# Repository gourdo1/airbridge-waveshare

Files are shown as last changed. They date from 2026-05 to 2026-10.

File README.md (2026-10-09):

# AirBridge

ESP32 bridge for ResMed AirSense 10 CPAP.

AirBridge feeding oximetry

## What it does

- **Web UI** - configure therapy settings, view sleep reports, live pressure/flow waveforms, and manage oximeters.
- **SD recording and export** - records therapy in Air10 EDF format and synchronizes files to SMB and SleepHQ on [SD-capable hardware](docs/hardware.md#what-needs-sd).
- **Oximetry** - feeds SpO2/pulse into AirSense for native SAD.edf recording. BLE (Nonin 3150, O2Ring, O2Ring-S, Checkme O2, WS20A, generic PLX/HR sensors) and UDP for integrating unsupported devices.
- **ResMed OTA** - upload and flash AirSense firmware over WiFi.
- **TCP-UART bridge** - send commands to AirSense over WiFi.

## First setup

Follow the [Quick Start](docs/quickstart.md) to wire and flash your board.
On a fresh installation, connect to its `airbridge_...` WiFi network
(password `airbridge`), open `http://192.168.4.1/`, and complete the setup wizard.
Default Web UI login: `admin` / `airbridge`.

## Related tools

[airbreak-plus](https://github.com/m-kozlowski/airbreak-plus/tree/master/python/) contains Python tools for direct serial/TCP interaction:

- `python/resmed_flash.py -p tcp:airbridge` - flash AirSense firmware
- `python/resmed_config.py -p tcp:airbridge` - read/write AirSense settings

Both support serial (`-p /dev/ttyUSB0`) and TCP (`-p tcp:hostname`) with `--tcp-mode=raw|transparent|text`.

## Screenshots

| Dashboard | Edf Sync | Charts |
|---|---|---|
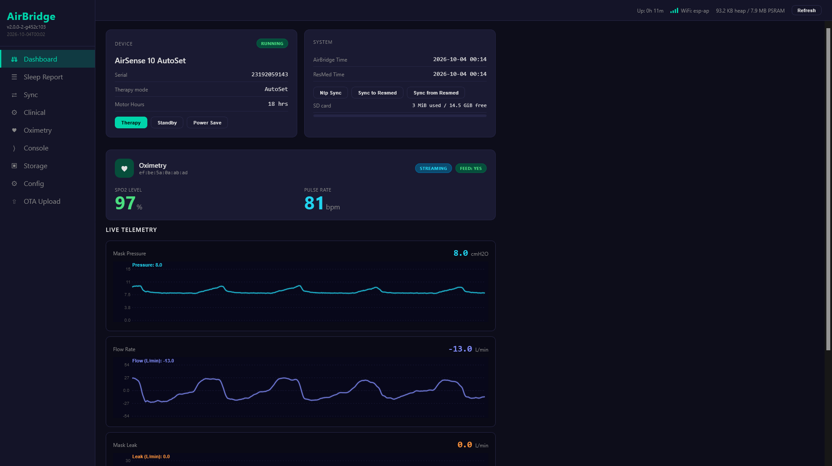
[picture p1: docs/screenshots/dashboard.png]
Dashboard
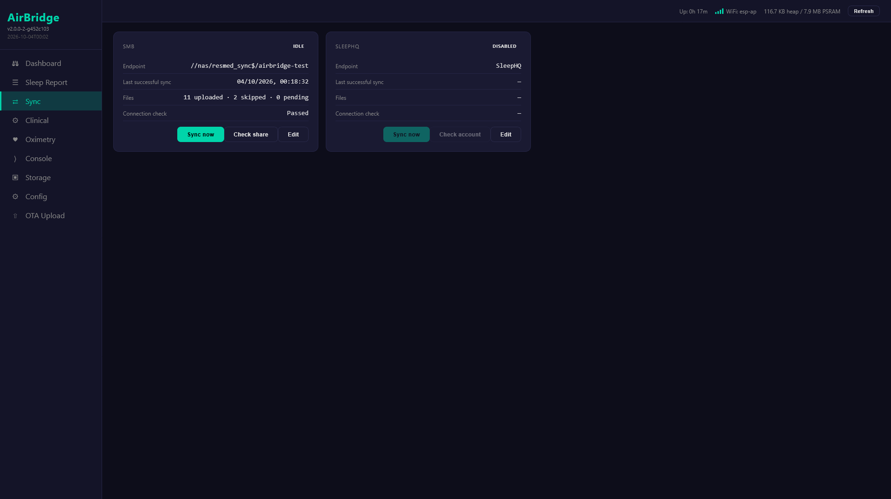
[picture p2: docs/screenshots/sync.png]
Sync
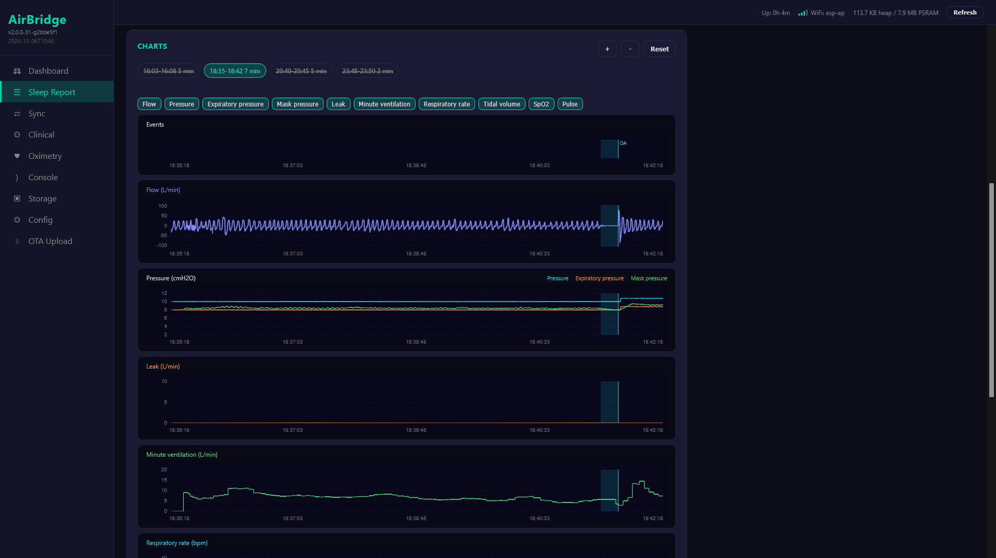
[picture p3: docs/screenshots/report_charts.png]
Charts
|  |  |  |

| Sleep Report | Clinical Settings | Oximetry |
|---|---|---|
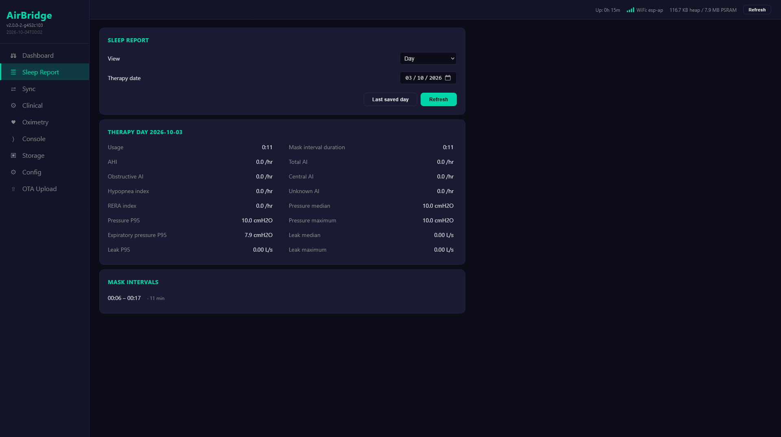
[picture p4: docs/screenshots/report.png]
Report
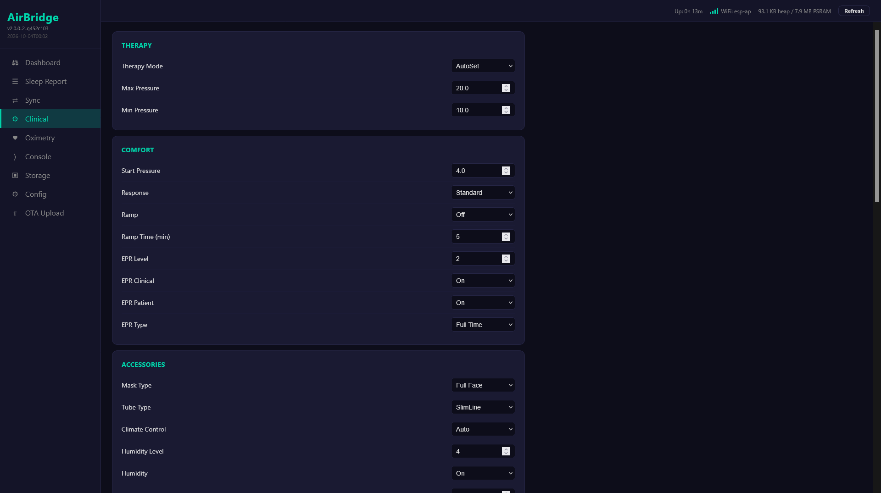
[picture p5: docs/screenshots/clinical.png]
Clinical
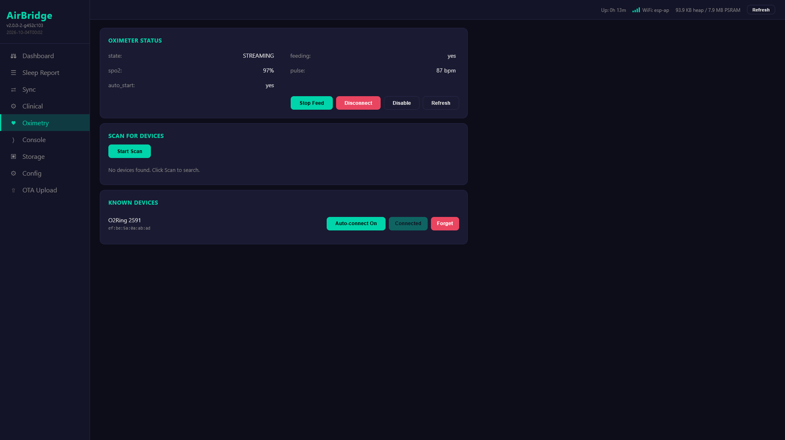
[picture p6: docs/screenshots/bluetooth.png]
Bluetooth
|  |  |  |

## License

GPL v3. See [LICENSE](LICENSE).

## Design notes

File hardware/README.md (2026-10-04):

# Hardware sources

User documentation: [docs/hardware.md](../docs/hardware.md).

| Path | Content |
|---|---|
| `wiring/{xiao_sd,xiao,pico}/` | hand-wired variants (schematic only, local symbol library) |
| `pcb/board_interface/` | interface board (edge card) |
| `pcb/board_main_xiao/` | XIAO main board |
| `pcb/gerbers/` | gerbers, per board as a directory and a ZIP |
| `pcb/assembly/` | JLCPCB BOM/CPL |
| `schematics/` | PDF and PNG export of each schematic |
| `renders/` | 3D renders of the boards |
| `enclosure/xiao/` | STL for the PCB variant |

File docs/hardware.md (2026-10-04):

# Hardware

AirBridge connects to the AirSense 10 edge connector: UART plus +24 V.

## Variants

In order of preference:

| Variant | Build env | SD | Docs |
|---|---|----|---|
| PCB: interface board + XIAO main board | `xiao-esp32s3-plus-sdmmc4` | yes | [hardware_pcb.md](hardware_pcb.md) |
| Hand-wired XIAO ESP32-S3 Plus + microSD | `xiao-esp32s3-plus-sdmmc4` | yes | [hardware_wiring.md](hardware_wiring.md#xiao-esp32-s3-plus--sd) |
| Waveshare ESP32-S3-GEEK | `waveshare-esp32-s3-geek` | onboard | [below](#waveshare-esp32-s3-geek) |
| Waveshare ESP32-S3-LCD-1.54 (UART pads) | `waveshare-s3-lcd154` | onboard | [below](#waveshare-esp32-s3-lcd-154) |
| Waveshare ESP32-S3-LCD-1.54 (SCL/SDA pads) | `waveshare-s3-lcd154-i2cpads` | onboard | [below](#alternate-wiring-sclsda-pads) |
| Hand-wired XIAO ESP32-S3 Plus | `xiao-esp32s3-plus` | no | [hardware_wiring.md](hardware_wiring.md#xiao-esp32-s3-plus-without-sd) |
| Hand-wired M5Stamp Pico (legacy) | `m5stamp-pico` | no | [hardware_wiring.md](hardware_wiring.md#m5stamp-pico-legacy) |

The PCB and the hand-wired XIAO + SD use the same GPIOs and the same firmware.

The M5Stamp Pico has no PSRAM and no SD support. It is kept building, but new
features are not designed around it.

## What needs SD

Requires SD:

- local therapy recording in AirSense EDF format (`DATALOG`, `STR.edf`,
  `Identification`)
- SMB export
- SleepHQ export
- Storage browser (list, download, ZIP, rename, delete)

Works without SD:

- UART/TCP bridge
- live pressure/flow charts
- oximetry (BLE, UDP)
- clinical settings
- Sleep Report
- ResMed OTA and AirBridge OTA

On builds without SD the Sync and Storage tabs are hidden and the SMB/SleepHQ
setup steps are skipped.

## AirSense 10 edge connector

| Left | Right |
|---|---|
| **Tx** | nc |
| **Rx** | **GND** |
| nc | nc |
| nc | nc |
| nc | **+24V**  |

UART: 3.3 V logic, 57600 8N1. AirSense Tx goes to AirBridge RX.

## GPIO

| Signal | XIAO ESP32-S3 Plus | M5Stamp Pico |
|---|---|---|
| UART RX (from AirSense Tx) | GPIO2 (D1) | G36 |
| UART TX (to AirSense Rx) | GPIO1 (D0) | G26 |
| LED | GPIO21 | G27 |

SD, 4-bit SDMMC (`xiao-esp32s3-plus-sdmmc4`):

| CLK | CMD | D0 | D1 | D2 | D3 |
|-----|-----|----|----|----|----|
| GPIO13 | GPIO11 | GPIO12 | GPIO38 | GPIO39 | GPIO40 |

Pins are set by build flags in `platformio.ini`; defaults are in
`include/board.h`. The XIAO SD clock is 40 MHz (`AB_SDMMC_FREQ_KHZ=40000`).

### Waveshare ESP32-S3-GEEK

16 MB flash, 2 MB PSRAM, onboard microSD. The LCD is not used; its backlight
is switched off.

| UART connector | AirSense |
|---|---|
| RX (GPIO44) | Tx |
| TX (GPIO43) | Rx |
| GND | GND |

The onboard card uses 4-bit SDMMC at 40 MHz:

| CLK | CMD | D0 | D1 | D2 | D3 |
|-----|-----|----|----|----|----|
| GPIO36 | GPIO35 | GPIO37 | GPIO33 | GPIO38 | GPIO34 |

Power through the USB-A connector with 5 V, not the AirSense 24 V supply.
Pinout: [Waveshare schematic](https://files.waveshare.com/wiki/ESP32-S3-GEEK/ESP32-S3-GEEK-Schematic1.pdf).

## Power

### XIAO through BAT

The XIAO is fed from a 5 V buck into its **BAT** pad, through a diode
(Schottky when hand-wired, LM66100 ideal diode on the PCB). No battery is
fitted.

- The **5V** pad is USB VBUS. Feeding it would push current into the USB host
  whenever a cable is connected. BAT is the board's own supply input.
- The diode keeps the XIAO charger and USB from backfeeding the buck.
- With the buck powered, BAT is held above the charger's regulation voltage,
  so the charger does not supply charging current.
- USB stays usable for flashing and logs with the device installed.

### Series resistor on +24 V

Hot-plugging a buck module into the AirSense charges its input capacitors hard
enough to trip the AirSense overcurrent protection, which shuts it down.
A ~47 Ω resistor in series with +24 V limits that inrush.

It works, but it is not an optimal solution: it drops voltage and dissipates
power continuously, so it needs a 2 W part. The PCB replaces it with the
eFuse soft-start; see [hardware_pcb.md](hardware_pcb.md#power).

## Waveshare ESP32-S3-LCD-1.54

The `waveshare-s3-lcd154` build target runs on the Waveshare
[ESP32-S3-LCD-1.54](https://www.waveshare.com/esp32-s3-lcd-1.54.htm) and its
touch variant. The AirSense UART uses the board's exposed UART pads:

| Signal | Waveshare pad | GPIO |
|---|---|---|
| AirSense Tx -> AirBridge RX | ESP_RXD | GPIO44 |
| AirSense Rx <- AirBridge TX | ESP_TXD | GPIO43 |
| AirSense GND | GND | - |

GPIO43/44 are the ESP32-S3 UART0 pins, so this target runs the console (logs,
`$` commands, provisioning) over the native USB-C port instead. Nothing but
AirSense traffic is sent on GPIO43 once the firmware is running.

### Alternate wiring: SCL/SDA pads

If the ESP_TXD/ESP_RXD pads are damaged, use the `waveshare-s3-lcd154-i2cpads`
build target (and `waveshare-s3-lcd154-i2cpads-ota` for WiFi updates) and wire
the AirSense to the SCL/SDA pads instead:

| Signal | Waveshare pad | GPIO |
|---|---|---|
| AirSense Tx -> AirBridge RX | SCL | GPIO41 |
| AirSense Rx <- AirBridge TX | SDA | GPIO42 |
| AirSense GND | GND | - |

Don't swap these. SCL/SDA are the board's I2C bus, shared with the IMU, the
audio codecs and (touch variant) the touch controller, with 4.7k pull-ups.
The firmware never uses that bus, but those chips still listen to it:

- I2C chips never drive SCL, so the AirSense's output on SCL is never fought.
- An I2C chip can pull SDA low to acknowledge. AirBridge therefore drives
  SDA open-drain and relies on the 4.7k pull-up for the high level, so
  nothing can short.
- The touch controller is held in reset (GPIO47) to take it off the bus.
- Rarely, when both sides transmit at once and the bits happen to match a
  chip's address, a chip may corrupt a byte. Commands fail their checksum and
  are retried, and a lost oximetry sample is replaced half a second later.

A side benefit: GPIO41/42 aren't the ESP32-S3 console pins, so the boot text
described below never reaches the AirSense on this wiring.

### Power

Set the step-down converter to **3.3V** and feed it into the board's **3V3
pad**, the same way as the M5Stamp Pico. This bypasses the board's own
USB/battery power path and its 3.3V regulator. Keep the 47 Ohm inrush resistor
on the +24V input.

- Trim the converter to 3.3V with a meter **before** connecting it. The 3V3
  rail feeds the ESP32-S3, flash, PSRAM and LCD directly with no protection,
  and 3.6V is the ESP32-S3 absolute maximum.
- Size the converter for at least 500mA. WiFi and BLE together draw short
  current peaks well above the average, and a sagging supply causes brownout
  resets.
- Don't leave a USB-C cable connected while the 3.3V feed is powered for long
  periods. With both connected, the onboard regulator and the external
  converter drive the 3V3 rail in parallel. A short USB flashing or serial
  session is fine, but for long debugging runs disconnect one of the two.
- Leave the battery header empty.

```

    AirSense 10                          Waveshare ESP32-S3-LCD-1.54
    Edge Connector                       +----------------------+
                                         |                      |
    Tx  -------------------------------- ESP_RXD pad (GPIO44)   |
    Rx  -------------------------------- ESP_TXD pad (GPIO43)   |
    GND ----------------+      +-------- GND pad                |
                        |      |    +--> 3V3 pad                |
    +24V ---[47R]--+    |      |    |    +----------------------+
                   |    |      |    |
               +---+----+------+----+----+
               |  IN+  IN-    OUT- OUT+  |
               |        MP1584EN         |
               |       (3.3V out)        |
               +-------------------------+
```

Notes:

- The LCD shows a status screen: IP address, time, AirSense state, mask
  pressure during therapy, and SpO2/pulse when an oximeter is feeding.
  The backlight runs at a low dim level. Pressing any of the three buttons
  (BOOT, GPIO4, GPIO5) raises it to full brightness for 10 seconds. It also
  stays bright for 10 seconds after boot so the IP address can be read. Tune
  the dim level with `-DAB_LCD_DIM_DUTY=<0-1023>` in `platformio.ini` if the
  default (8) is too dark or too bright.
- While therapy is running, the screen subscribes to the AirSense's 25 Hz
  pressure stream (the same one the web UI's live graph uses) and shows a
  one-second average.
- GPIO2 (battery power latch) is driven high at boot. This only matters when
  the board runs from a LiPo, and does nothing when powered through the 3V3 pad.
- The ESP32-S3 boot ROM prints a short burst of text on GPIO43 at 115200 baud
  right after reset, before the firmware starts. The AirSense sees it as line
  noise and the firmware's health polling recovers. If it ever causes trouble,
  the ROM output can be disabled permanently by burning the
  `UART_PRINT_CONTROL` eFuse (irreversible).
- The onboard TF card slot is used for SD recording and export (see
  [What needs SD](#what-needs-sd)). It is 4-bit SDMMC at 20 MHz:

  | CLK | CMD | D0 | D1 | D2 | D3 |
  |-----|-----|----|----|----|----|
  | GPIO16 | GPIO15 | GPIO17 | GPIO18 | GPIO13 | GPIO14 |

- Partition table: `partitions_s3_16mb.csv` (two 7.75 MB app slots plus a
  crash-dump partition). A board still on the older 8 MB layout keeps working
  after a WiFi update, but only gets the new layout (and crash dumps) after
  one USB flash of the complete image: `pio run -e <env> -t upload`, or
  `pio run -e <env> -t initialbin` and then `firmware.factory.bin` at
  address `0x0` in a web flasher.

## Enclosure

3D-printable enclosure for the PCB variant:
[airbridge-xiao.stl](../hardware/enclosure/xiao/airbridge-xiao.stl).

## Sources

KiCad projects, PDFs, gerbers and assembly files are in
[`hardware/`](../hardware/README.md).

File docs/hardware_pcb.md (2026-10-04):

# PCB

Two boards:

- **interface**: edge card that plugs into the AirSense 10. Protected 24 V
  input, 5 V buck, UART.
- **main**: XIAO ESP32-S3 Plus and 4-bit microSD.

The boards are joined by a 5-pin, 1.27 mm solder-pin connector.
Build env: `xiao-esp32s3-plus-sdmmc4`. GPIO and SD features:
[hardware.md](hardware.md).

| Interface | Main |
|---|---|
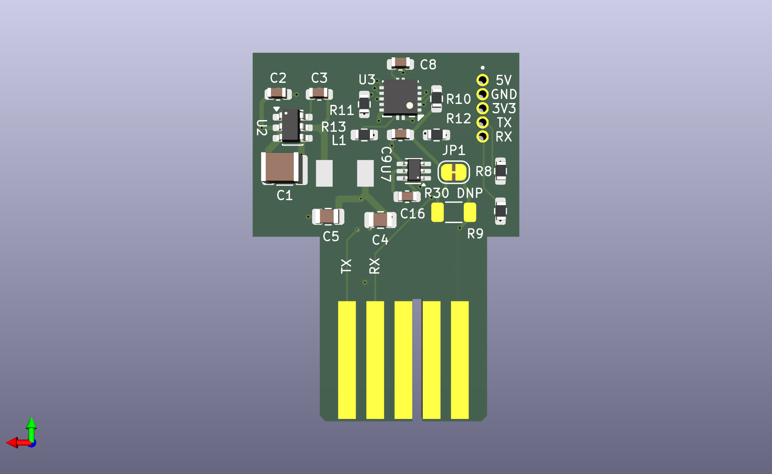
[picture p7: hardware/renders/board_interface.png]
interface board
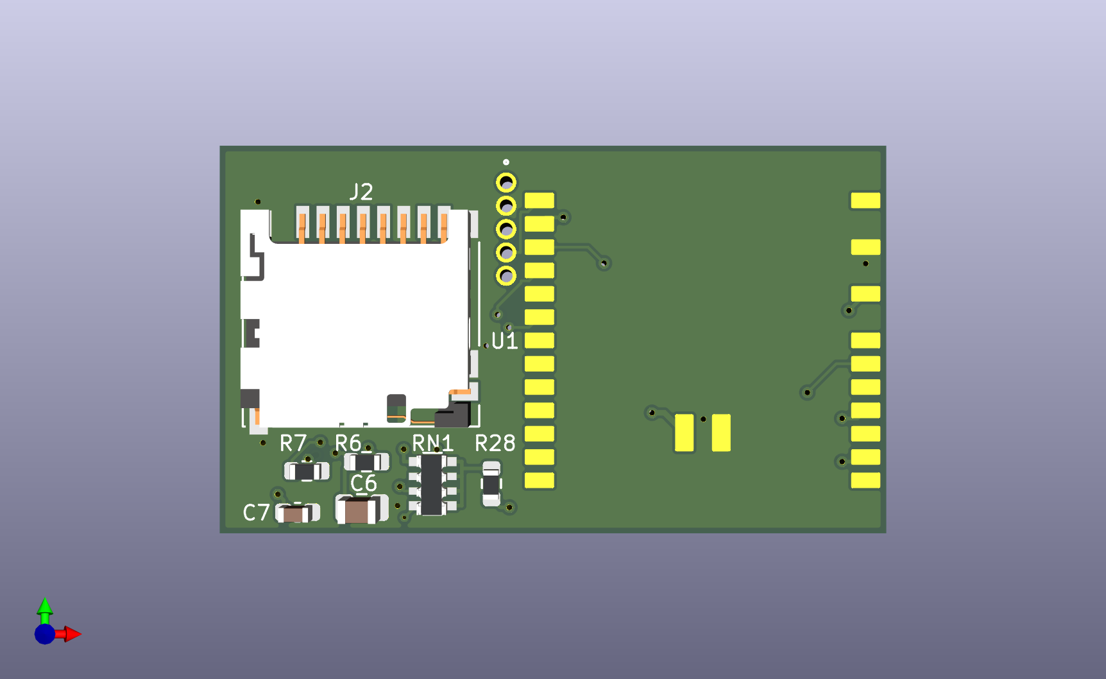
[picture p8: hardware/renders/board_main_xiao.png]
main board
|  |  |

## Interface board

[KiCad project](../hardware/pcb/board_interface/),
PDF: [board_interface.pdf](../hardware/schematics/board_interface.pdf).

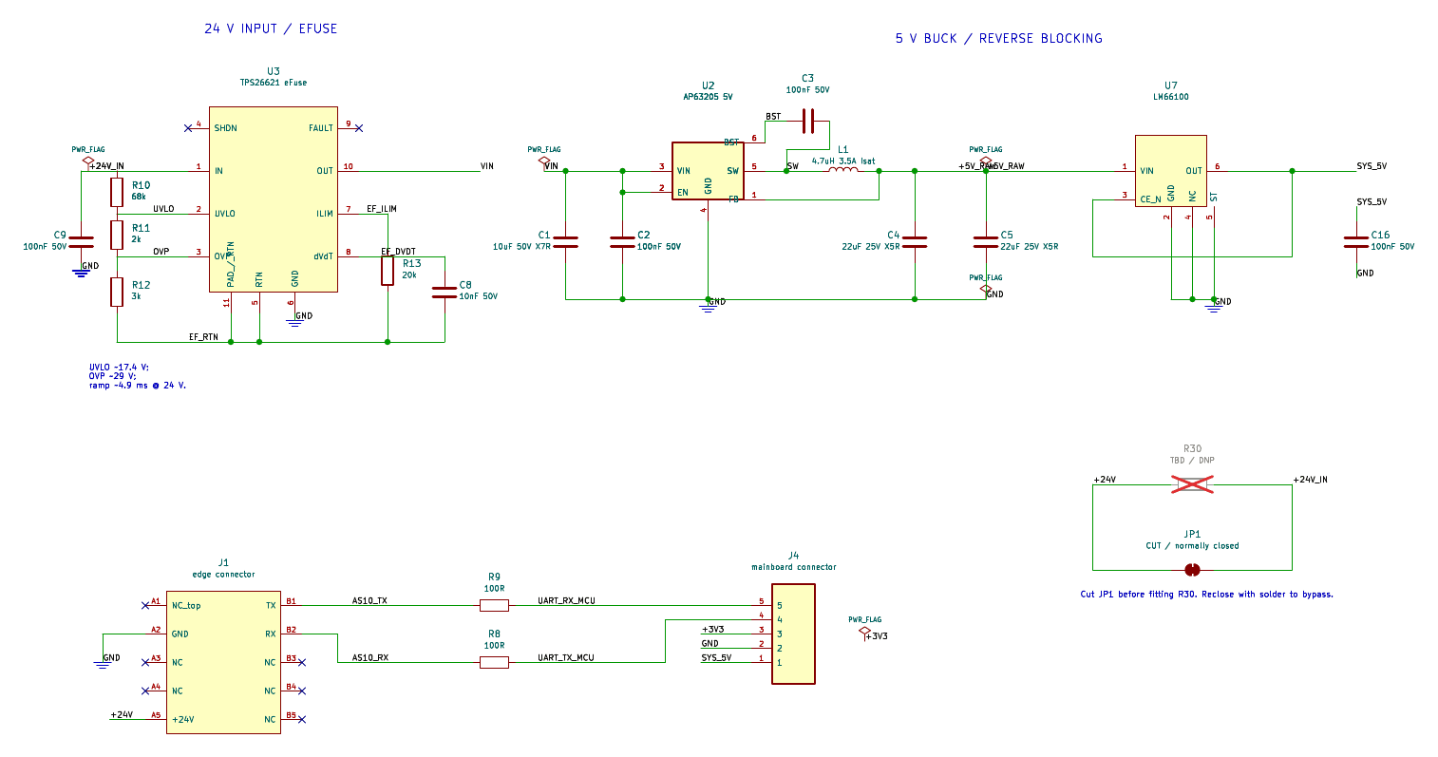
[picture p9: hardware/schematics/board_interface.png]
interface schematic


### Power

- **TPS26621 eFuse** on +24 V: UVLO ~17.4 V, OVP ~29 V, dV/dt soft-start
  ~4.9 ms at 24 V. The soft-start replaces the series resistor used in
  hand-wired builds, so hot-plugging does not trip the AirSense.
- **AP63205** 5 V buck.
- **LM66100** ideal diode between the buck and `SYS_5V`. It does the job of the
  Schottky in hand-wired builds, without the drop.

R30 (1206, not fitted) is an optional series resistor on +24 V, bypassed by
the JP1 solder jumper. Cut JP1 before fitting R30; bridge it with solder to
go back.

### UART

AirSense TX/RX go through 100 Ω series resistors to the interboard connector.

### Interboard connector

| Pin | Signal |
|-----|---|
| 1 | SYS_5V |
| 2 | GND |
| 3 | +3V3 |
| 4 | UART_TX_MCU (to AirSense RX) |
| 5 | UART_RX_MCU (from AirSense TX) |

## Main board

[KiCad project](../hardware/pcb/board_main_xiao/),
PDF: [board_main_xiao.pdf](../hardware/schematics/board_main_xiao.pdf).

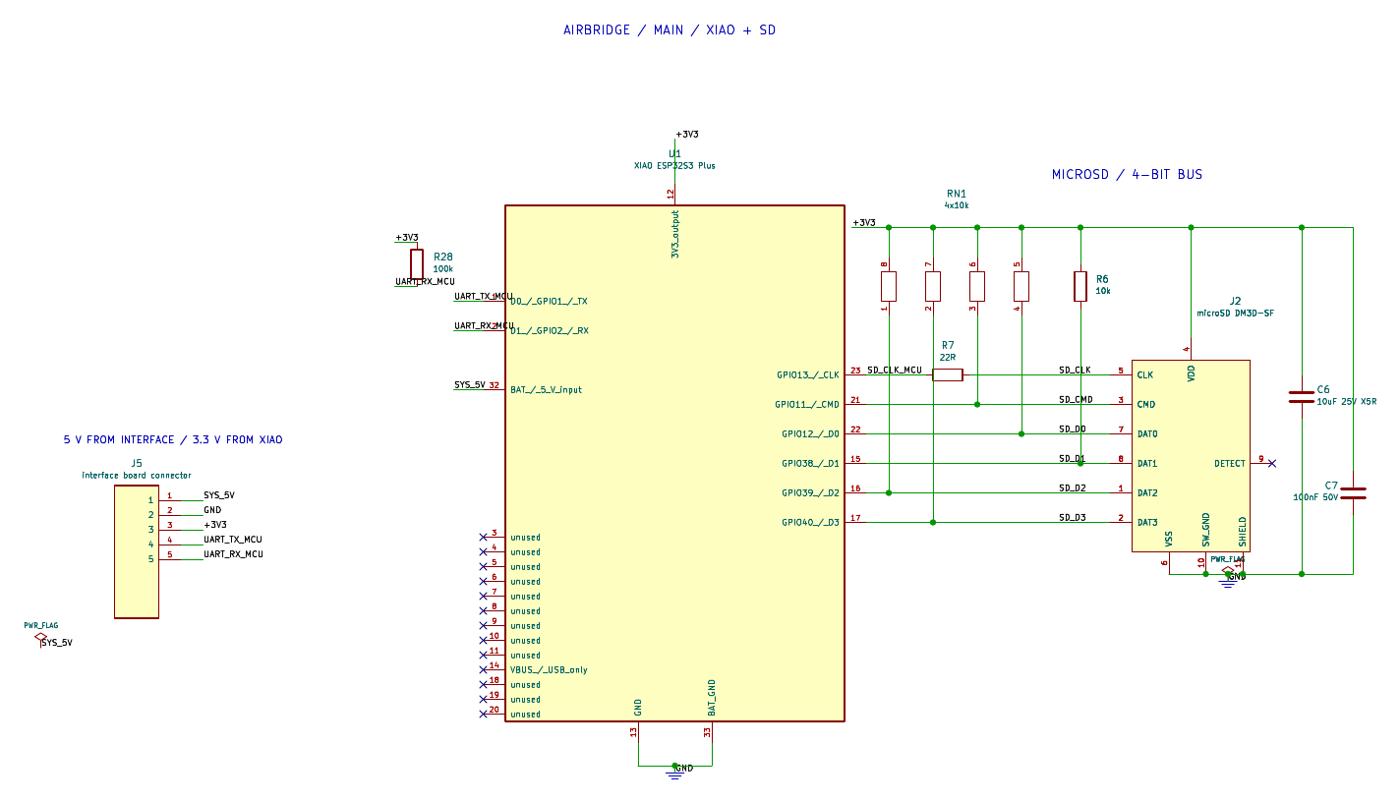
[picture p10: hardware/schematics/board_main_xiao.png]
main schematic


- XIAO ESP32-S3 Plus soldered onto pads; `SYS_5V` feeds its BAT input (see
  [hardware.md](hardware.md#xiao-through-bat)).
- Hirose DM3D-SF microSD socket powered from XIAO 3V3.
- 10 kΩ pull-ups on CMD and D0–D3, 22 Ω series resistor on CLK, 10 µF +
  100 nF at the socket.
- 100 kΩ pull-up on UART RX.

## Ordering

Both boards: 4 layers, 1.6 mm. Tinned (HASL) edge fingers are good enough.

| Board | Gerbers | BOM | CPL |
|---|---|-----|-----|
| interface | [interface.zip](../hardware/pcb/gerbers/interface.zip) | [bom-interface.csv](../hardware/pcb/assembly/bom-interface.csv) | [cpl-interface.csv](../hardware/pcb/assembly/cpl-interface.csv) |
| main | [main_xiao.zip](../hardware/pcb/gerbers/main_xiao.zip) | [bom-main-xiao.csv](../hardware/pcb/assembly/bom-main-xiao.csv) | [cpl-main-xiao.csv](../hardware/pcb/assembly/cpl-main-xiao.csv) |

BOM/CPL are in JLCPCB format with LCSC part numbers. Not included: the XIAO
module and the interboard pins, both soldered by hand.

Enclosure: [airbridge-xiao.stl](../hardware/enclosure/xiao/airbridge-xiao.stl).

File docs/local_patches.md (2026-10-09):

# Local patches to third-party code

Workarounds for bugs in libraries or frameworks that AirBridge builds
against. Each entry says how to tell when the upstream fix has landed, so the
local copy can be removed. Check this list whenever the pioarduino platform
or Arduino core version in `platformio.ini` changes, and before merging
upstream AirBridge.

## SD_MMC drops `SDMMC_HOST_FLAG_DEINIT_ARG` (arduino-esp32)

| | |
|---|---|
| Patched | 2026-10-07 |
| Where | [`lib/SD_MMC/`](../lib/SD_MMC/README.md), copied from arduino-esp32 3.3.7 |
| Affects | Every SD-capable build. Visible on Waveshare ESP32-S3-LCD-1.54, where GPIO0 is a button |
| Symptom | After an SD unmount or failed mount, GPIO0's input buffer is switched off and the left button reads as permanently pressed. `$LCD` shows `ie=0 pu=1` for GPIO0 |
| Cause | `SDMMCFS::begin()` overwrites `host.flags`, losing `SDMMC_HOST_FLAG_DEINIT_ARG`; ESP-IDF then calls `sdmmc_host_deinit_slot()` without a slot number and may release the unused slot 0, resetting GPIO0 |
| Upstream status | Not fixed in arduino-esp32 3.3.7, 3.3.12 or `master` (2026-10-07) |
| Remove when | The arduino-esp32 version AirBridge builds against keeps `SDMMC_HOST_FLAG_DEINIT_ARG` in `SD_MMC.cpp`. Then delete `lib/SD_MMC/` and this entry |

Details and the exact two-line change: [`lib/SD_MMC/README.md`](../lib/SD_MMC/README.md).

## `.patch` files checked out as CRLF on Windows (upstream AirBridge)

| | |
|---|---|
| Patched | 2026-10-09 |
| Where | [`.gitattributes`](../.gitattributes): `*.patch text eol=lf` |
| Affects | Every build on Windows with `core.autocrlf=true`, all targets |
| Symptom | Build fails in `python/tools/library_patches.py` (`git apply` returns an error) while generating `WebResponses.cpp` |
| Cause | Upstream v2.1.1 applies `patches/espasyncwebserver/*.patch` with `git apply` at build time. Git converts the patch to CRLF on checkout; the library source is LF, so no hunk matches |
| Upstream status | No `.gitattributes` in upstream v2.1.1 (2026-10-09) |
| Remove when | Upstream adds an equivalent rule (any `.gitattributes` that keeps `*.patch` LF), or stops applying patches with `git apply`. Then drop this file or merge it with upstream's |

## Build middleware ignored on Windows (pioarduino platform)

| | |
|---|---|
| Patched | 2026-10-09 |
| Where | [`python/tools/extend_asyncwebserver.py`](../python/tools/extend_asyncwebserver.py) (upstream AirBridge script, fork-modified) |
| Affects | Every build on Windows, all targets |
| Symptom | Build fails in `library_patches.py`: `git apply` reports `.../generated/tmpXXXX/WebResponses.cpp: No such file or directory` (the temp folder holds `ColorFormat.c`) |
| Cause | On Windows, pioarduino 55.03.37 (`builder/frameworks/arduino.py`, `integrated_middleware`) replaces all registered build middlewares with one wrapper that calls each of them for every source file, ignoring their patterns, and compiles the original source, ignoring the node they return. Upstream's middleware therefore ran for the wrong file, and its patched replacement would never be compiled anyway |
| Fix | The middleware checks the file name itself, and on Windows applies the patch to the installed library copy in place (once; a reverse `git apply --check` detects an applied patch). Linux/macOS keep upstream's generated-copy behaviour |
| Upstream status | Present in pioarduino 55.03.37 and upstream AirBridge v2.1.1 (2026-10-09) |
| Remove when | pioarduino honours middleware patterns and return values on Windows, or upstream AirBridge handles Windows itself. Then restore upstream's `extend_asyncwebserver.py` |

After adding the `.gitattributes` rule, refresh existing checkouts once:
`git rm --cached -r patches && git checkout -- patches` (or delete the `.patch`
files and `git checkout -- patches`).

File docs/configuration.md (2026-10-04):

# Configuration

Settings are stored in NVS (non-volatile storage) and persist across reboots.

## How to configure

**Web UI:** Config tab -> choose a category -> edit fields -> Save & Persist

**CLI:** `$CONFIG key value` then `$CONFIG SAVE`

**Provisioning:** Copy `provision.env.example` to `provision.env`, fill in
your values, and flash. `provision.py` runs after the upload completes and
applies each line via the appropriate command:

- Most keys go through `$CONFIG key value`.
- `wifi_net=SSID PASSWORD` is routed through `$WIFI ADD ssid pass`. Use
  shell-style double quotes if either field contains spaces:
  `wifi_net="My Network" "correct horse battery staple"`. Multiple
  `wifi_net=` lines provision multiple networks (up to 4). Provisioning
  appends; existing networks on the device are kept.

## Settings reference

### WiFi & Network

WiFi networks are managed as a list (up to 4 SSIDs) via the web UI's WiFi
Networks card or the `$WIFI ADD ssid pass` / `$WIFI REMOVE N` commands. The
top-level WiFi-related config keys are:

| Key | Default | Description |
|-----|---|---|
| `hostname` | airbridge | DHCP hostname and AP SSID prefix |
| `wifi_mode` | 1 | Operating mode, see table below |
| `wifi_roam` | true | Roam automatically between saved networks |
| `wifi_country` | 01 | ISO 3166 country code; "01" = worldwide |

**`wifi_mode` values:**

| Value | Name | Behavior |
|---|---|---|
| 0 | auto | Connect to a saved network; use AP fallback while disconnected. |
| 1 | AP only | Access point only; does not connect to saved networks. |
| 2 | off | WiFi disabled entirely (serial/UART only). |
| 3 | STA only | Connect to saved networks without AP fallback. |
| 4 | STA+AP always | Keep the access point available while connecting to saved networks. |

The softAP (when used) is named `<hostname>_<MAC>` with password `airbridge`,
and serves the web UI at `192.168.4.1`.

With no saved networks, Auto and STA+AP modes provide an access point for
setup. STA-only does not start an access point.

The `wifi_country` key affects channel allocation and TX power limits per
regulatory domain. Use a 2-letter ISO code (`US`, `DE`, `JP`, `PL`, ...) or
`01` to use the worldwide-safe defaults. Bad values are rejected with a
log warning and the previous setting stays in effect.

### Web UI

| Key | Default | Description |
|-----|---|---|
| `http_port` | 80 | Web server port |
| `http_user` | admin | Web UI username |
| `http_pass` | airbridge | Web UI password |

### OTA

| Key | Default | Description |
|-----|---|---|
| `update_url` | GitHub latest-release manifest | Release manifest URL; empty disables update checks |

Update checks are automatic. Installing an available update requires
confirmation on the OTA tab.

### Time & Timezone

| Key | Default | Description |
|-----|---|---|
| `ntp_server` | *(empty)* | NTP server address. Empty = use DHCP-provided server, or pool.ntp.org as fallback |
| `tz` | UTC0 | POSIX timezone string (e.g. `CET-1CEST,M3.5.0,M10.5.0/3`) |
| `resmed_time` | 1 | Automatically synchronize the ResMed clock from NTP while idle. `0` disables automatic synchronization; manual sync remains available |

**Config > Time** includes a helper for detecting your browser's timezone.

If NTP is unavailable, the ResMed clock supplies an approximate time for
AirBridge, independently of `resmed_time`.

### Storage export

SMB and SleepHQ export require SD support and a mounted card. Both are disabled
by default. Automatic export sends pending recordings after startup and therapy,
only while therapy is inactive.

| Key | Default | Description |
|-----|---|---|
| `smb_enabled` | false | Enable SMB export |
| `smb_auto_after_therapy` | true | Automatically sync pending recordings after startup and therapy |
| `smb_endpoint` | *(empty)* | Destination in `//host/share/optional/path` form |
| `smb_user` | *(empty)* | SMB username |
| `smb_password` | *(empty)* | SMB password |
| `sleephq_enabled` | false | Enable SleepHQ export |
| `sleephq_auto_after_therapy` | true | Automatically sync pending recordings after startup and therapy |
| `sleephq_client_id` | *(empty)* | SleepHQ API client ID |
| `sleephq_client_secret` | *(empty)* | SleepHQ API client secret |
| `sleephq_team_id` | *(empty)* | Optional numeric team ID; current team is resolved when empty |
| `sleephq_device_id` | *(empty)* | Optional SleepHQ device ID attached to new imports |

### Oximetry

| Key | Default | Description |
|-----|---|---|
| `oxi_enabled` | true | Enable BLE oximeter support |
| `oxi_auto_start` | true | Start feeding data automatically on connect |
| `oxi_feed_therapy_only` | false | Only inject readings during active therapy |
| `oxi_interval_ms` | 500 | Injection interval in milliseconds |
| `oxi_lframe_continuous` | true | Send L-frames even when no valid reading (keeps link alive) |
| `udp_oxi_port` | 8025 | UDP oximetry listener port, 0 = disabled |

BLE oximeters are managed from the **Oximetry** tab. For UDP oximetry, see [udp_oximetry.md](udp_oximetry.md).

Only one source feeds at a time. First to deliver data wins, 10 seconds of silence releases.

### UART

| Key | Default | Description |
|-----|---|---|
| `tcp_port` | 23 | TCP command port |
| `allow_transparent_during_therapy` | false | Allow raw UART passthrough during therapy |
| `uart_cmd_timeout_ms` | 500 | Command response timeout |

### Logging

| Key | Default | Description |
|-----|---|---|
| `debug_port` | 8023 | Debug log stream port (read-only) |
| `syslog_en` | 0 | Enable UDP syslog forwarding |
| `syslog_host` | *(empty)* | Syslog server IPv4 address; required for forwarding |
| `syslog_port` | 514 | Syslog server UDP port (1-65535) |

## CLI commands

All commands are prefixed with `$`. Anything without `$` is sent to the AirSense as a Q-frame command.

| Command | Description |
|---|---|
| `$STATUS` | System state, oximetry, UART stats, heap |
| `$TIME` | Show UTC, local time, timezone, NTP sync state |
| `$TIMESYNC` | Re-trigger ResMed clock sync from NTP |
| `$OXI SCAN` | Scan for BLE oximeters |
| `$OXI RESULTS` | Show scan results |
| `$OXI CONNECT [addr]` | Connect to oximeter |
| `$OXI DISCONNECT` | Disconnect oximeter |
| `$OXI START` / `STOP` | Start/stop data injection |
| `$OXI STATUS` | Oximeter connection details |
| `$CONFIG` | Dump all config |
| `$CONFIG key` | Get single value |
| `$CONFIG key value` | Set value (not saved until SAVE) |
| `$CONFIG SAVE` | Persist to NVS |
| `$CONFIG RESET` | Reset all to defaults |
| `$EXPORT STATUS` | Show SMB and SleepHQ state, progress, and last error |
| `$EXPORT SMB` | Sync pending recordings to SMB |
| `$EXPORT SLEEPHQ` | Sync pending recordings to SleepHQ |
| `$WIFI` / `$WIFI STATUS` | Connection state, RSSI, roaming flag |
| `$WIFI LIST` | List configured networks |
| `$WIFI ADD ssid pass` | Add a network (max 4) |
| `$WIFI REMOVE N` | Remove network at index N |
| `$WIFI HINTS` | Show cached BSSID/channel/PMF hints |
| `$WIFI HINTS CLEAR` | Drop all cached hints |
| `$FLASH [block] [FORCE]` | Flash uploaded ResMed firmware |
| `$FLASH STATUS` | Flash progress |
| `$FLASH CANCEL` | Abort flash |
| `$LOG` | Show log levels |
| `$LOG category level` | Set log level (ERROR/WARN/INFO/DEBUG) |
| `$TRANSPARENT` | Raw UART passthrough (60s idle timeout) |
| `$FRAMED` | Switch to framed UART mode |
| `$VERSION` | Firmware version |
| `$REBOOT` | Restart device |

Log categories: `GENERAL`, `OXI`, `TCP`, `WIFI`, `OTA`, `WEB`, `ARB`, `HEALTH`,
`EXPORT`, `EDF`, `STREAM`, `STORAGE`, `TIME`, `CONFIG`, `REPORT`, `ALL`

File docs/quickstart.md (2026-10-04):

# Quick Start

## What you need
- AirBridge hardware: the PCB, or a hand-wired XIAO ESP32-S3 Plus with or
  without SD. See [hardware.md](hardware.md) for variants and which features
  need SD.
- AirSense 10 with edge connector access
- A computer with Chrome or Edge and a USB data cable

## Wiring

PCB: [hardware_pcb.md](hardware_pcb.md).
Hand-wired: [hardware_wiring.md](hardware_wiring.md).

## Flash firmware

Download the `-initial.zip` matching your board from the
[latest release](https://github.com/m-kozlowski/airbridge/releases/latest)
and extract the `-initial.bin` image.

Open [ESPWebTool](https://esptool.spacehuhn.com/) in Chrome or Edge:

1. Connect the board over USB. M5Stamp Pico needs a 3.3 V USB-to-serial adapter.
2. Select **Connect** and choose its serial port.
3. Add the extracted `-initial.bin` at address `0x0`.
4. Select **Program** and wait for flashing to finish.

### Build from source instead

Install PlatformIO and check out the matching release tag.

XIAO with SD (PCB or hand-wired):

```bash
pio run -e xiao-esp32s3-plus-sdmmc4 -t upload
```

XIAO without SD:

```bash
pio run -e xiao-esp32s3-plus -t upload
```

M5Stamp Pico (legacy):

```bash
pio run -e m5stamp-pico -t upload
```

Waveshare ESP32-S3-LCD-1.54, AirSense wired to the UART pads or to the
SCL/SDA pads (see [hardware.md](hardware.md#waveshare-esp32-s3-lcd-154)).
These boards are not in the release images, so always build from source:

```bash
pio run -e waveshare-s3-lcd154 -t upload
pio run -e waveshare-s3-lcd154-i2cpads -t upload
```

If the upload can't connect, hold **BOOT** while plugging in the USB cable.
The USB port briefly disappears while the board resets after flashing; if the
automatic provisioning step misses it, run `python provision.py <serial port>`
again by hand.

## Configure WiFi

On a fresh installation, connect to the `airbridge_...` WiFi access point
(password `airbridge`) and open `http://192.168.4.1/`.

Log in with username `admin` and password `airbridge`. The setup wizard guides
you through your WiFi network, AirSense connection, time, optional sync
destinations, and Web UI credentials. Use **Save & next**, then **Finish**.
You can reopen the wizard from **Config > Initial setup**.

When flashing with PlatformIO, you can instead copy `provision.env.example`
to `provision.env` and fill in your WiFi credentials before flashing. These
settings are applied automatically after the USB upload.

## Verify it works

Once connected to your WiFi, open `http://airbridge/`. If the hostname does
not resolve, use the device IP from your router's DHCP leases.

The **Dashboard** should show the AirSense name and serial number. With the
AirSense powered on, connected, and not running therapy, its state is
`IDLE`.

See [Configuration](configuration.md) for available settings.

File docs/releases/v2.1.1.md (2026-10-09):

### Reliability fixes

- Fixed stalled or interrupted file and ZIP downloads from Storage.
- Fixed rare crash during Bluetooth initialization.

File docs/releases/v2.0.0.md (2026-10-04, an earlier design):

### EDF recording and synchronization

Record AirSense 10 therapy directly to AirBridge's microSD card in
ResMed-compatible EDF format, with automatic synchronization to an SMB
share, SleepHQ, or both.

Requires an SD-capable build and a microSD card in AirBridge.

### New hardware

AirBridge now has a dedicated two-board PCB design: an interface board that
plugs into the AirSense 10 and provides power and UART, and a XIAO ESP32-S3
Plus main board with microSD for EDF recording. KiCad sources, manufacturing
files, and a printable enclosure are included.

Waveshare ESP32-S3-GEEK is also supported, using its onboard microSD slot.

M5Stamp Pico remains a legacy build without EDF recording or synchronization.

### Upgrading

AirBridge firmware updates now use HTTP through the Web UI or the Python
flasher. ArduinoOTA and its dedicated upload environments have been removed.
SmartConfig has been replaced by setup through the AirBridge access point.

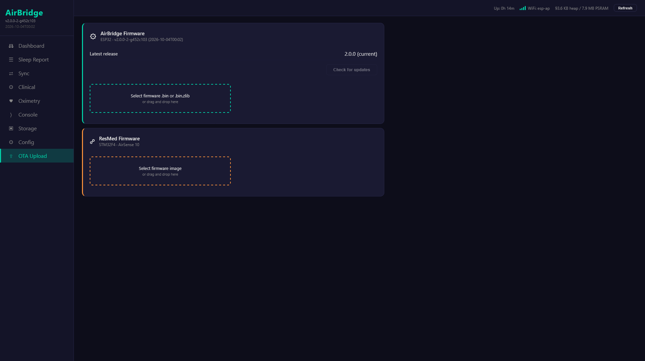
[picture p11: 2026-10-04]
docs/screenshots/ota.png

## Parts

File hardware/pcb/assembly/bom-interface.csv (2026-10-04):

Comment | Designator | Footprint | LCSC Part # | Quantity
CL32B106KBJNNNE | C1 | C_1210_3225Metric | C138687 | 1
CC0603KRX7R9BB104 | C2,C3,C9,C16 | C_0603_1608Metric | C14663 | 4
CL21A226MAQNNNE | C4,C5 | C_0805_2012Metric | C45783 | 2
0603B103K500NT | C8 | C_0603_1608Metric | C57112 | 1
SRP4020TA-4R7M | L1 | L_SRP4020TA | C2041623 | 1
0603WAF1000T5E | R8,R9 | R_0603_1608Metric | C22775 | 2
0603WAF6802T5E | R10 | R_0603_1608Metric | C23231 | 1
0603WAF2001T5E | R11 | R_0603_1608Metric | C22975 | 1
0603WAF3001T5E | R12 | R_0603_1608Metric | C4211 | 1
0603WAF2002T5E | R13 | R_0603_1608Metric | C4184 | 1
AP63205WU-7 | U2 | SOT-23-6 | C2071056 | 1
TPS26621DRCR | U3 | VSON-10-1EP_3x3mm_P0.5mm_EP1.65x2.4mm | C1848341 | 1
LM66100DCKR | U7 | SOT-363_SC-70-6 | C2869734 | 1

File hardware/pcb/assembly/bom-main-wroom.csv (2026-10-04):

Comment | Designator | Footprint | LCSC Part # | Quantity
CL21A106KAYNNNE | C6,C14,C17 | C_0805_2012Metric | C15850 | 3
CC0603KRX7R9BB104 | C7,C11,C15,C18,C19 | C_0603_1608Metric | C14663 | 5
CL10A105KB8NNNC | C10,C12 | C_0603_1608Metric | C15849 | 2
CL21A226MAQNNNE | C20,C21 | C_0805_2012Metric | C45783 | 2
PMEG6010CEH,115 | D1 | D_SOD-123F | C110797 | 1
BZT52C5V1 | D2 | D_SOD-123 | C699211 | 1
DM3D-SF | J2 | microSD_HC_Hirose_DM3D-SF | C719027 | 1
USB4110-GF-A | J3 | USB_C_Receptacle_GCT_USB4110 | C5143397 | 1
SRP4020TA-4R7M | L2 | L_SRP4020TA | C2041623 | 1
0603WAF1002T5E | R6,R16,R24 | R_0603_1608Metric | C25804 | 3
0603WAF220JT5E | R7,R19,R20 | R_0603_1608Metric | C23345 | 3
0603WAF3002T5E | R14,R15 | R_0603_1608Metric | C22984 | 2
0603WAF5101T5E | R17,R18 | R_0603_1608Metric | C23186 | 2
0603WAF1003T5E | R21,R23,R28 | R_0603_1608Metric | C25803 | 3
0603WAF1503T5E | R22 | R_0603_1608Metric | C22807 | 1
4D03WGJ0103T5E | RN1 | R_Array_Convex_4x0603 | C29718 | 1
ESP32-S3-WROOM-1U-N16R8 | U1 | WROOM_1U_03mm_vias | C3013946 | 1
TPS2553DBVR | U4 | SOT-23-6 | C55266 | 1
USBLC6-2SC6 | U5 | SOT-23-6 | C7519 | 1
AP63203WU-7 | U8 | SOT-23-6 | C780769 | 1

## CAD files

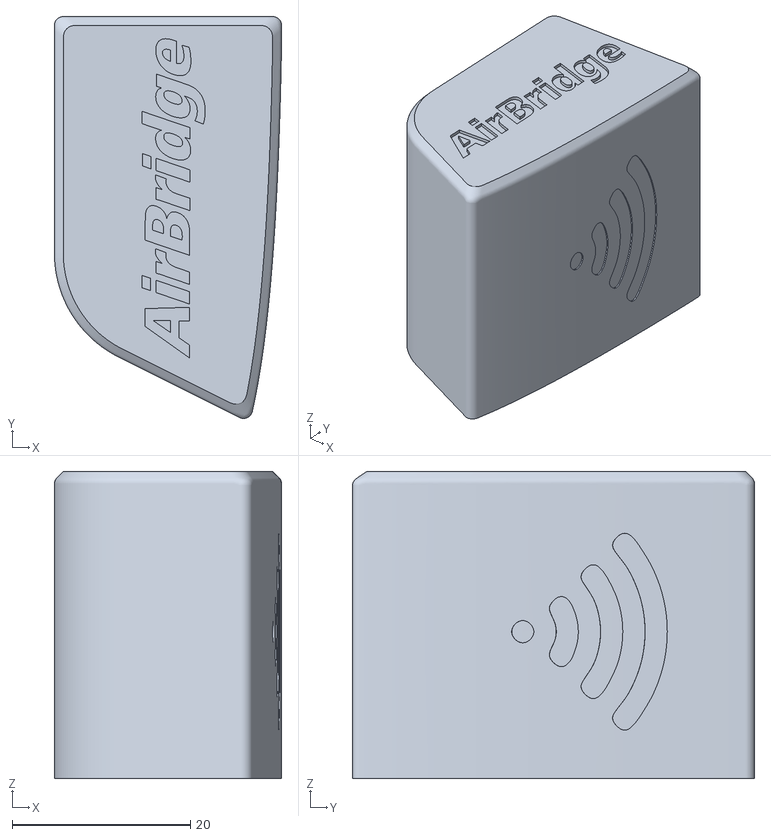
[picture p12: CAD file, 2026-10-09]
hardware/enclosure/ratsnest-SD/as10-side-adapter-ratsnest.stl
25.5 x 45.2 x 34.5

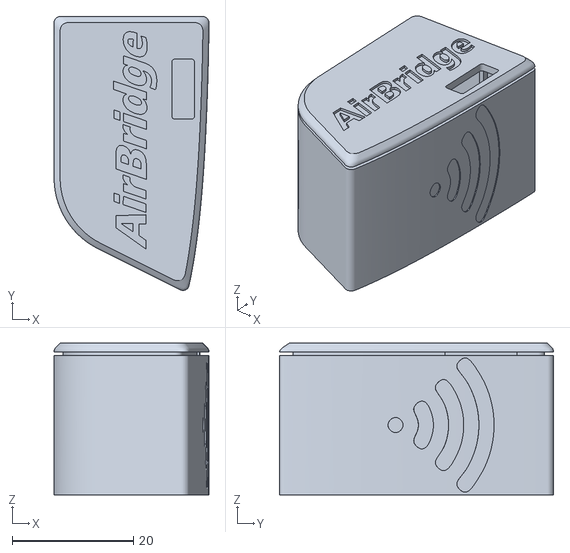
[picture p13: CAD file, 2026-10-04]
hardware/enclosure/xiao/airbridge-xiao.stl
25.5 x 45.2 x 25.0

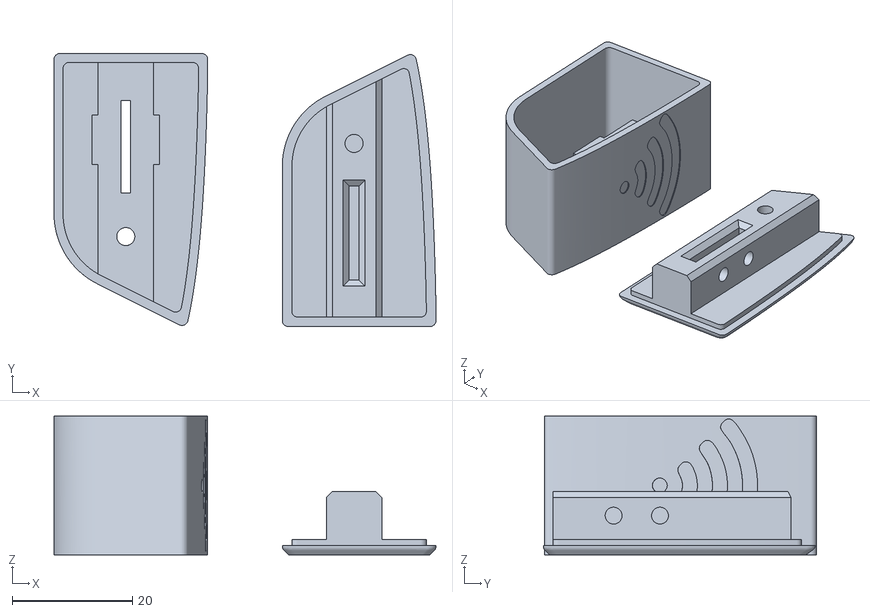
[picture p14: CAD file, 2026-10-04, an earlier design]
hardware/enclosure/legacy/makeshift_enclosure.stl
63.4 x 45.3 x 23.0

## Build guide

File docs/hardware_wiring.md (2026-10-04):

# Hand-wired hardware

Point-to-point wiring with ready-made modules. For the pinout, SD features and
power rationale see [hardware.md](hardware.md).

Each variant has a KiCad 9 project with its local symbol library and a PDF.
Module symbols show solder-pad names, not IC pin numbers.

## XIAO ESP32-S3 Plus + SD

Build env: `xiao-esp32s3-plus-sdmmc4`.
[KiCad project](../hardware/wiring/xiao_sd/),
PDF: [wiring_xiao_sd.pdf](../hardware/schematics/wiring_xiao_sd.pdf).

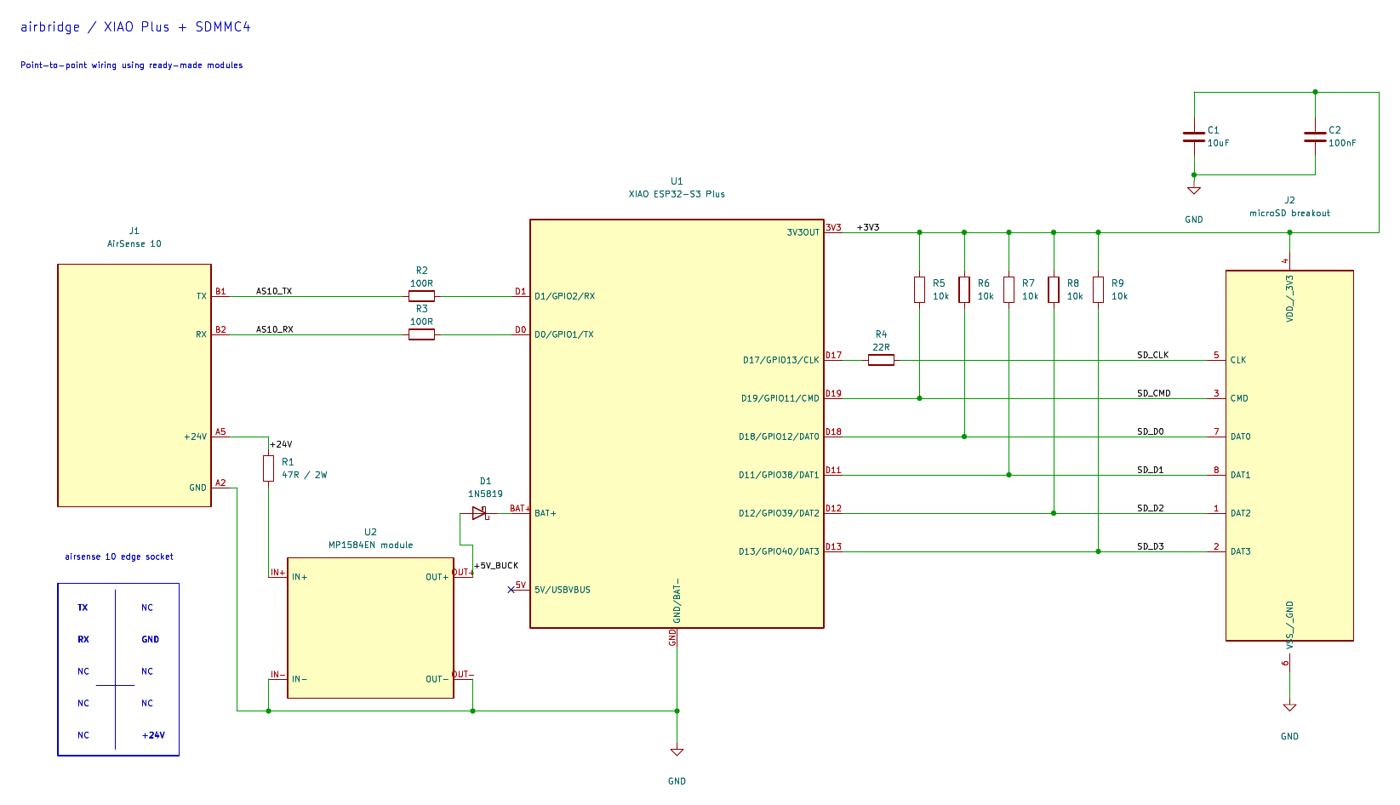
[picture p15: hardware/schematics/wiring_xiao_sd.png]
XIAO + SD wiring


Parts:

- Seeed XIAO ESP32-S3 Plus
- MP1584EN buck module
- 1N5819 Schottky diode
- 47 Ω / 2 W resistor
- 2× 100 Ω (UART)
- passive 3.3 V microSD breakout exposing all eight contacts
- 5× 10 kΩ, 22 Ω, 10 µF, 100 nF (SD)

Power:

- set the buck to **5.0 V before connecting the diode**
- diode cathode (band) to **BAT+**
- leave the **5V** pad unconnected

SD:

- the breakout must be passive and bring out DAT1 and DAT2. Six-pin SPI
  modules (with level shifter/regulator) do not work.
- pull-ups on CMD and DAT0–DAT3, 22 Ω in series with CLK, decoupling at the
  socket.
- keep SD wires short. With long leads build with `AB_SDMMC_FREQ_KHZ=20000`.

## XIAO ESP32-S3 Plus without SD

Build env: `xiao-esp32s3-plus`.
[KiCad project](../hardware/wiring/xiao/),
PDF: [wiring_xiao_no-sd.pdf](../hardware/schematics/wiring_xiao_no-sd.pdf).

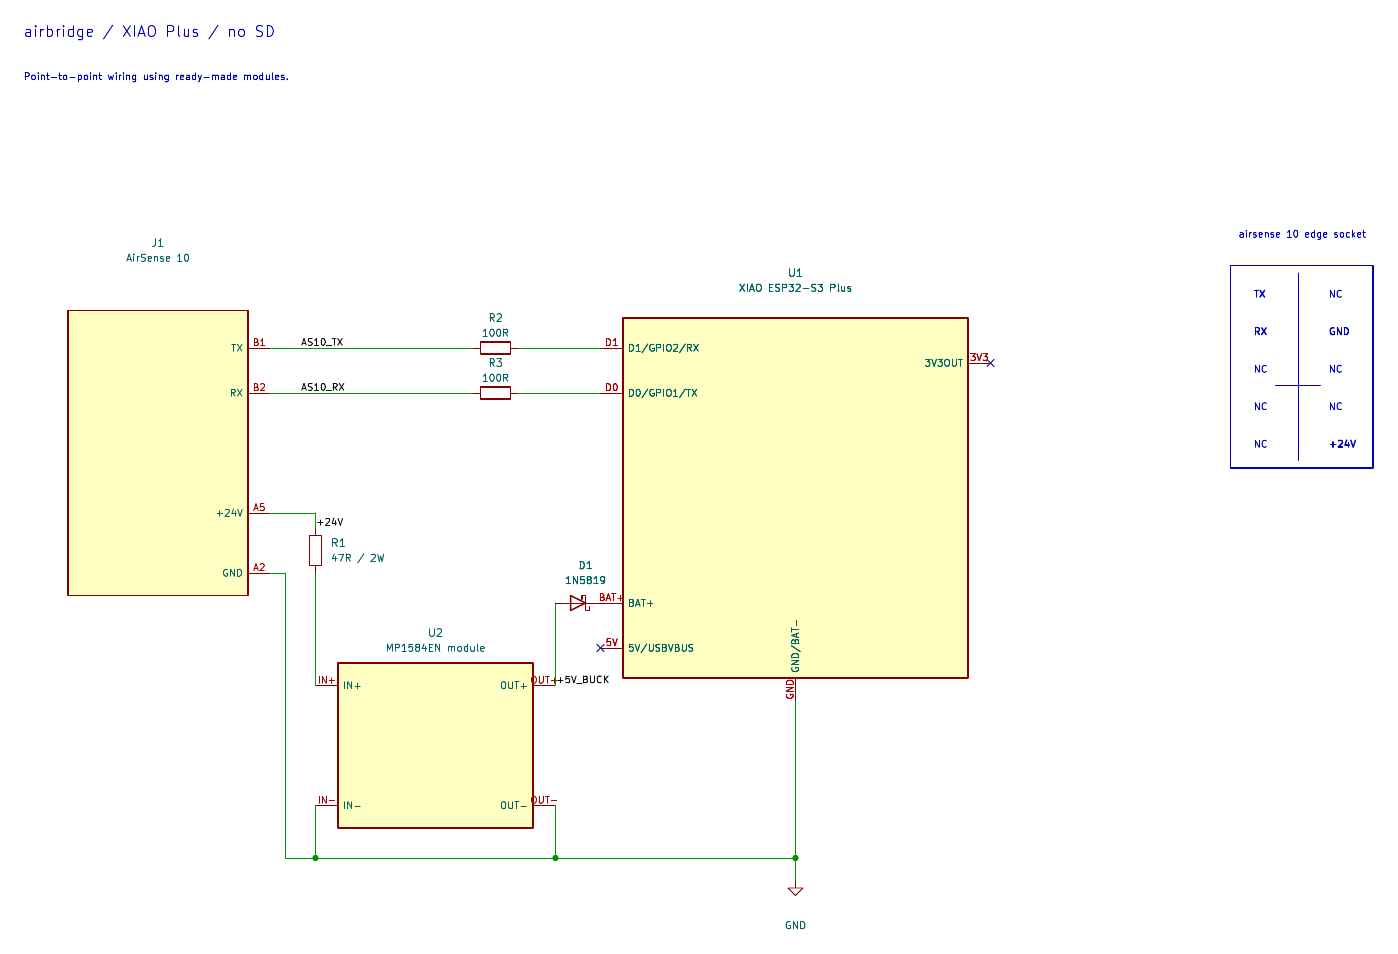
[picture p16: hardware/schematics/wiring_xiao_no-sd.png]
XIAO wiring


Same as above without the SD part.

## M5Stamp Pico (legacy)

Build env: `m5stamp-pico`.
[KiCad project](../hardware/wiring/pico/),
PDF: [wiring_pico.pdf](../hardware/schematics/wiring_pico.pdf).

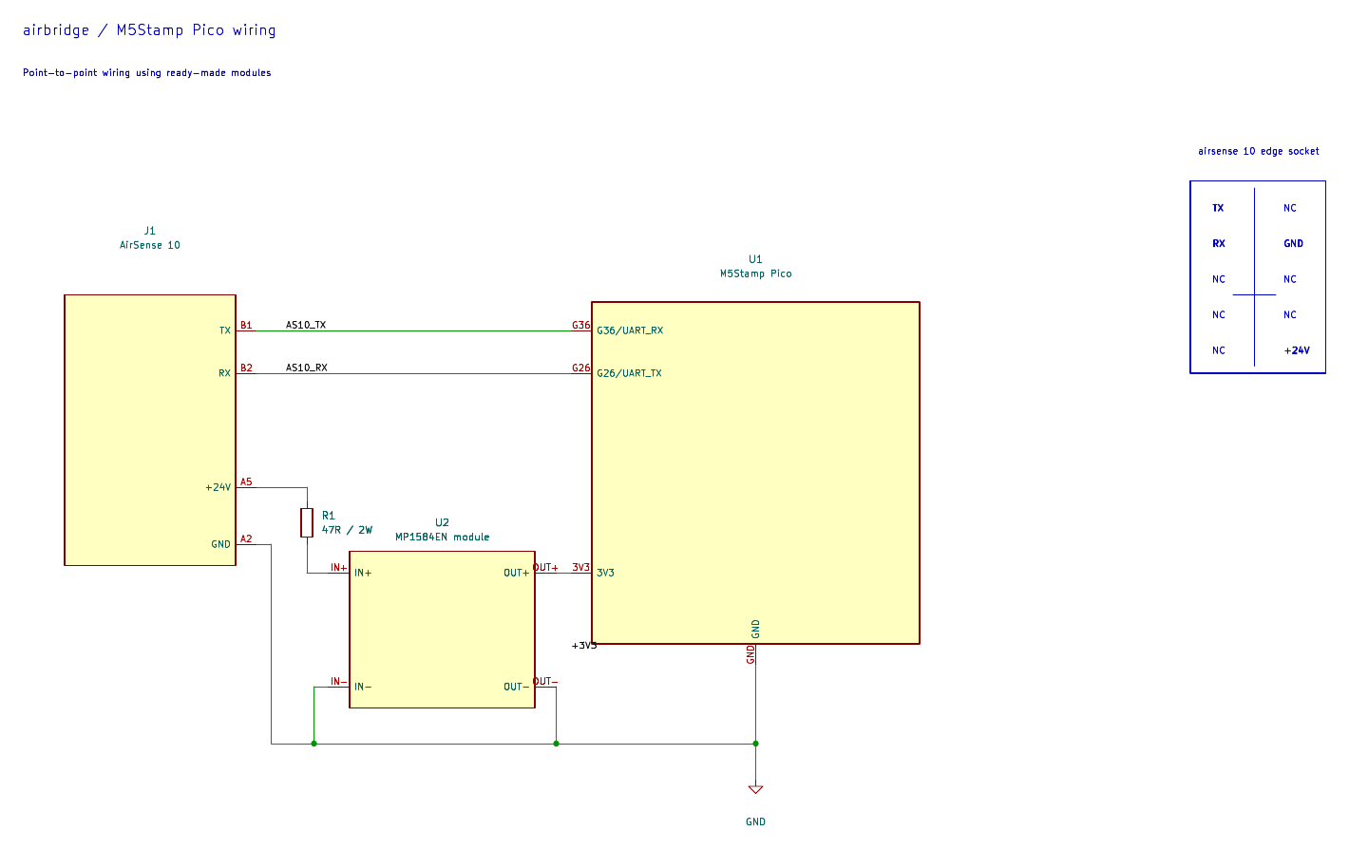
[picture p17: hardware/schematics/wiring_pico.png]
M5Stamp Pico wiring


MP1584EN set to **3.3 V**, output straight to the Pico 3V3 pin. 47 Ω / 2 W
in series with +24 V. Any 24 V to 3.3 V buck able to supply 300 mA+ will do.

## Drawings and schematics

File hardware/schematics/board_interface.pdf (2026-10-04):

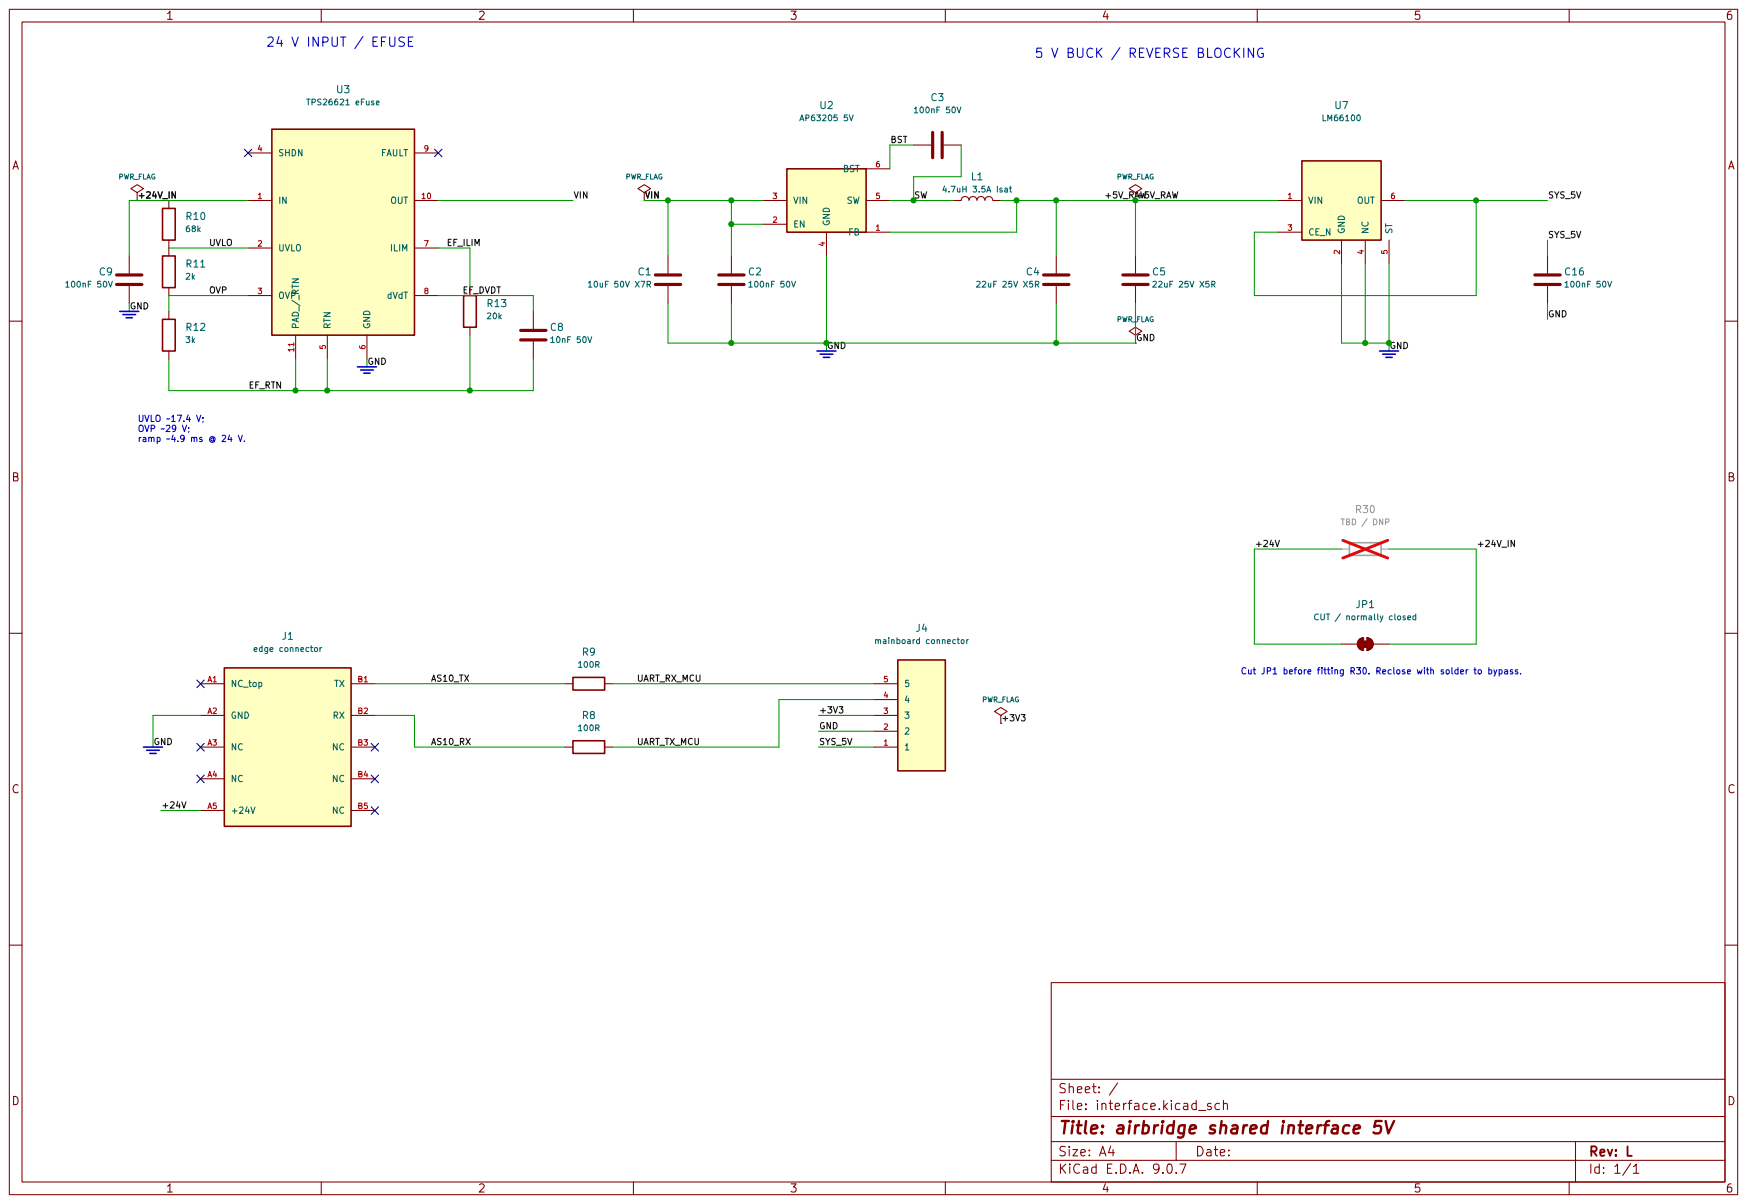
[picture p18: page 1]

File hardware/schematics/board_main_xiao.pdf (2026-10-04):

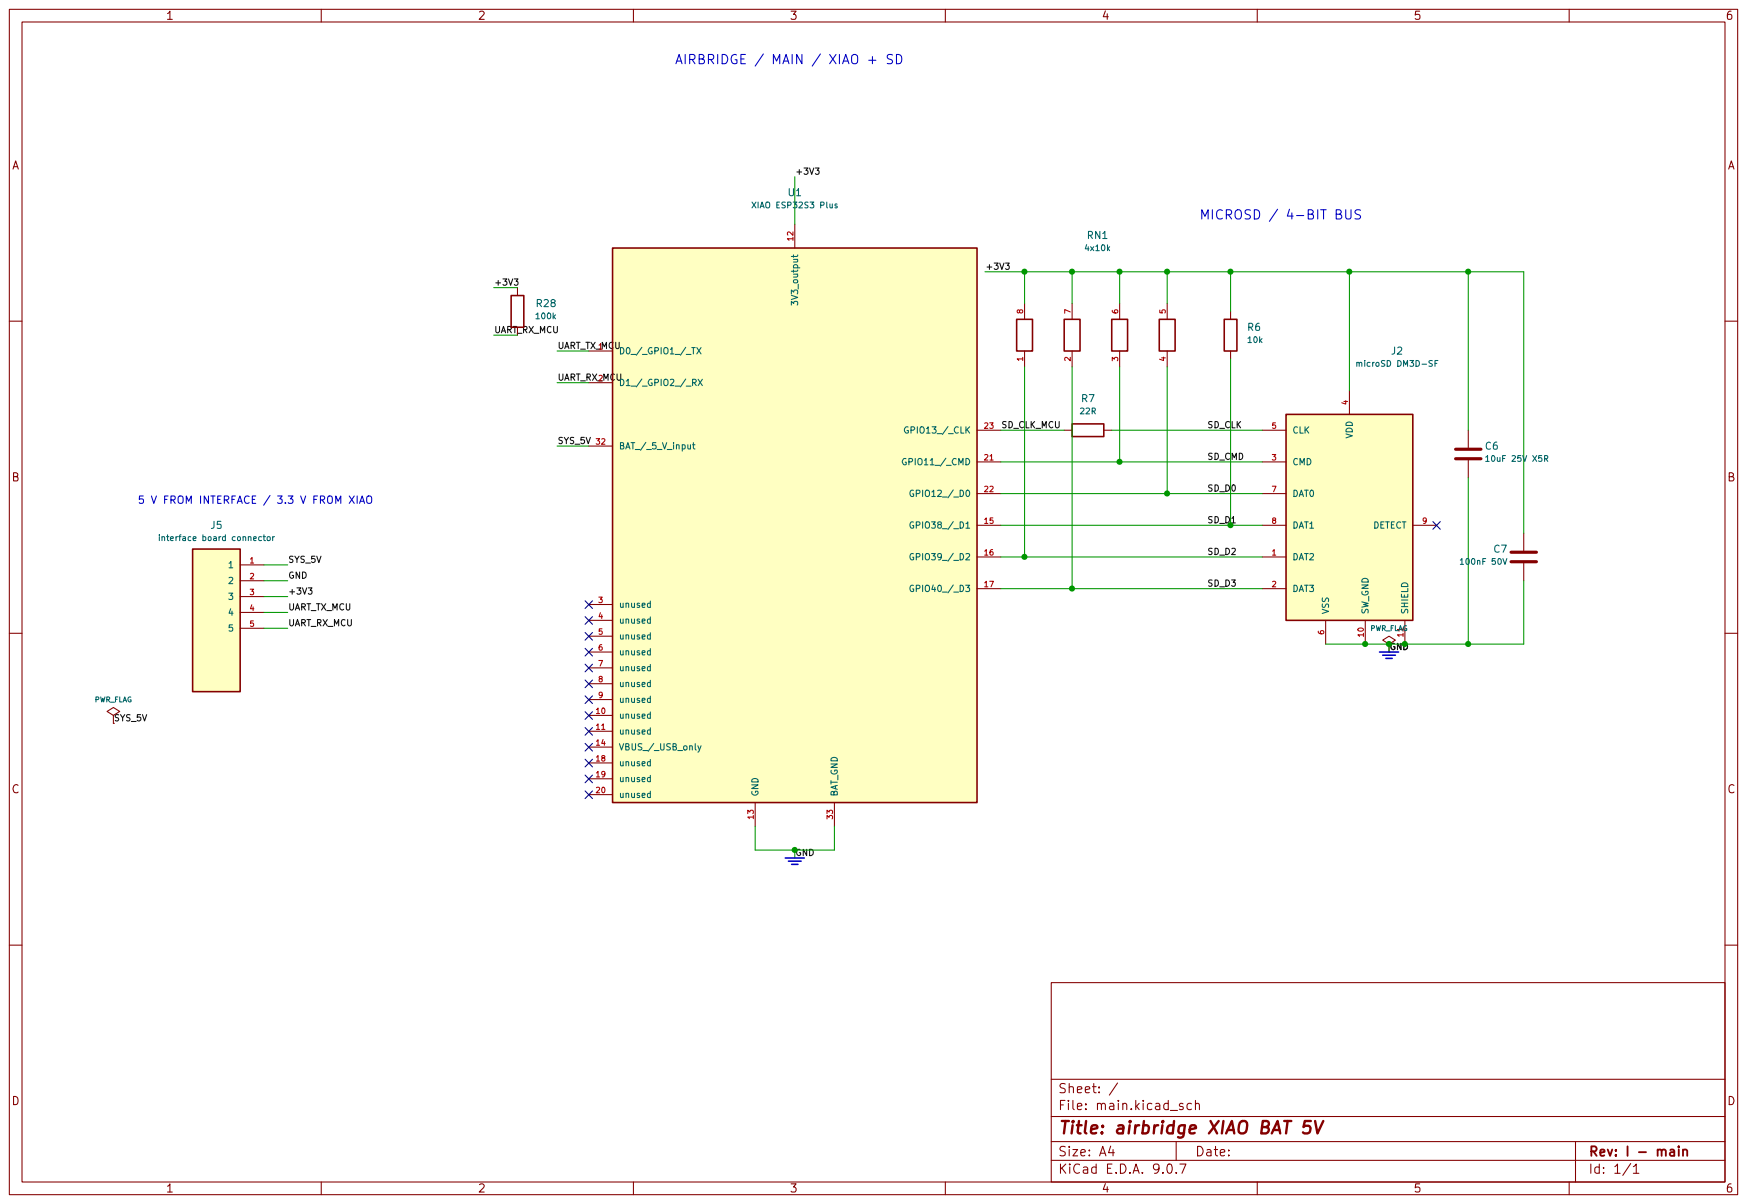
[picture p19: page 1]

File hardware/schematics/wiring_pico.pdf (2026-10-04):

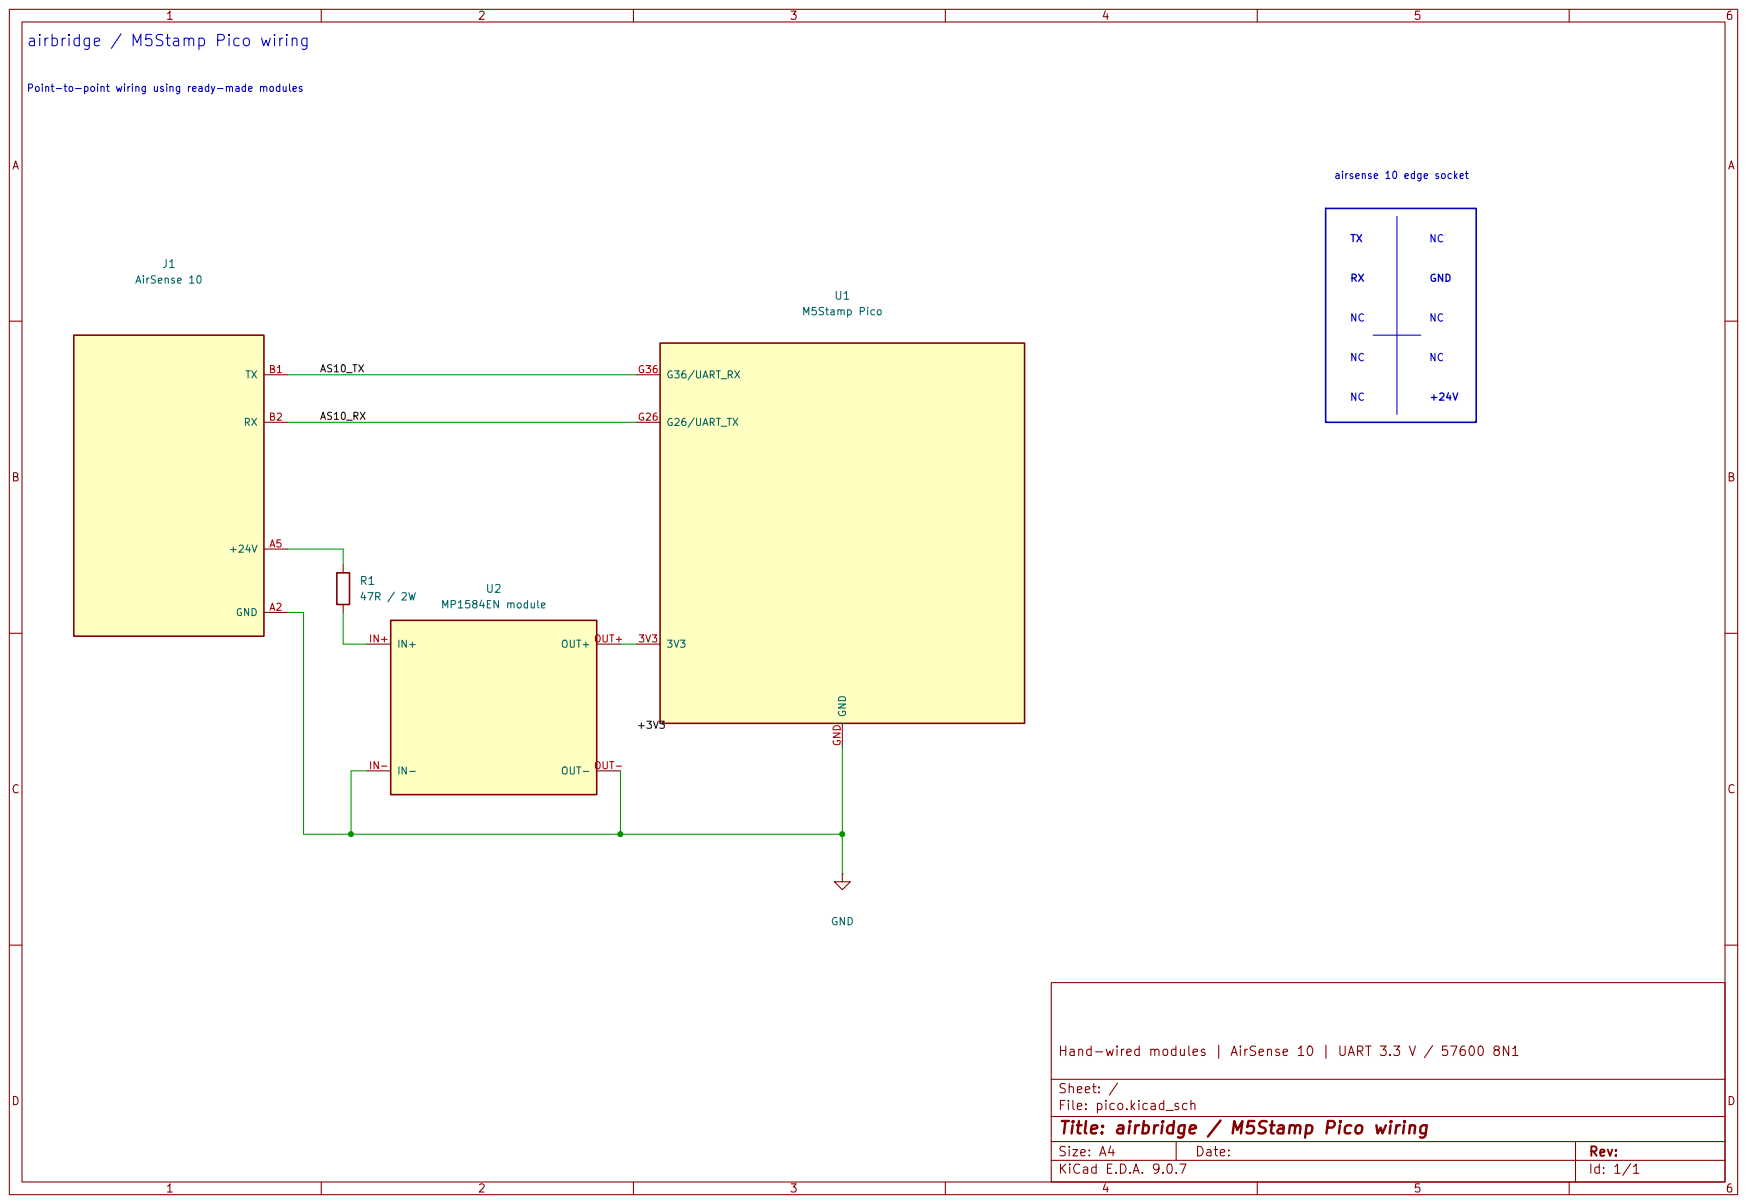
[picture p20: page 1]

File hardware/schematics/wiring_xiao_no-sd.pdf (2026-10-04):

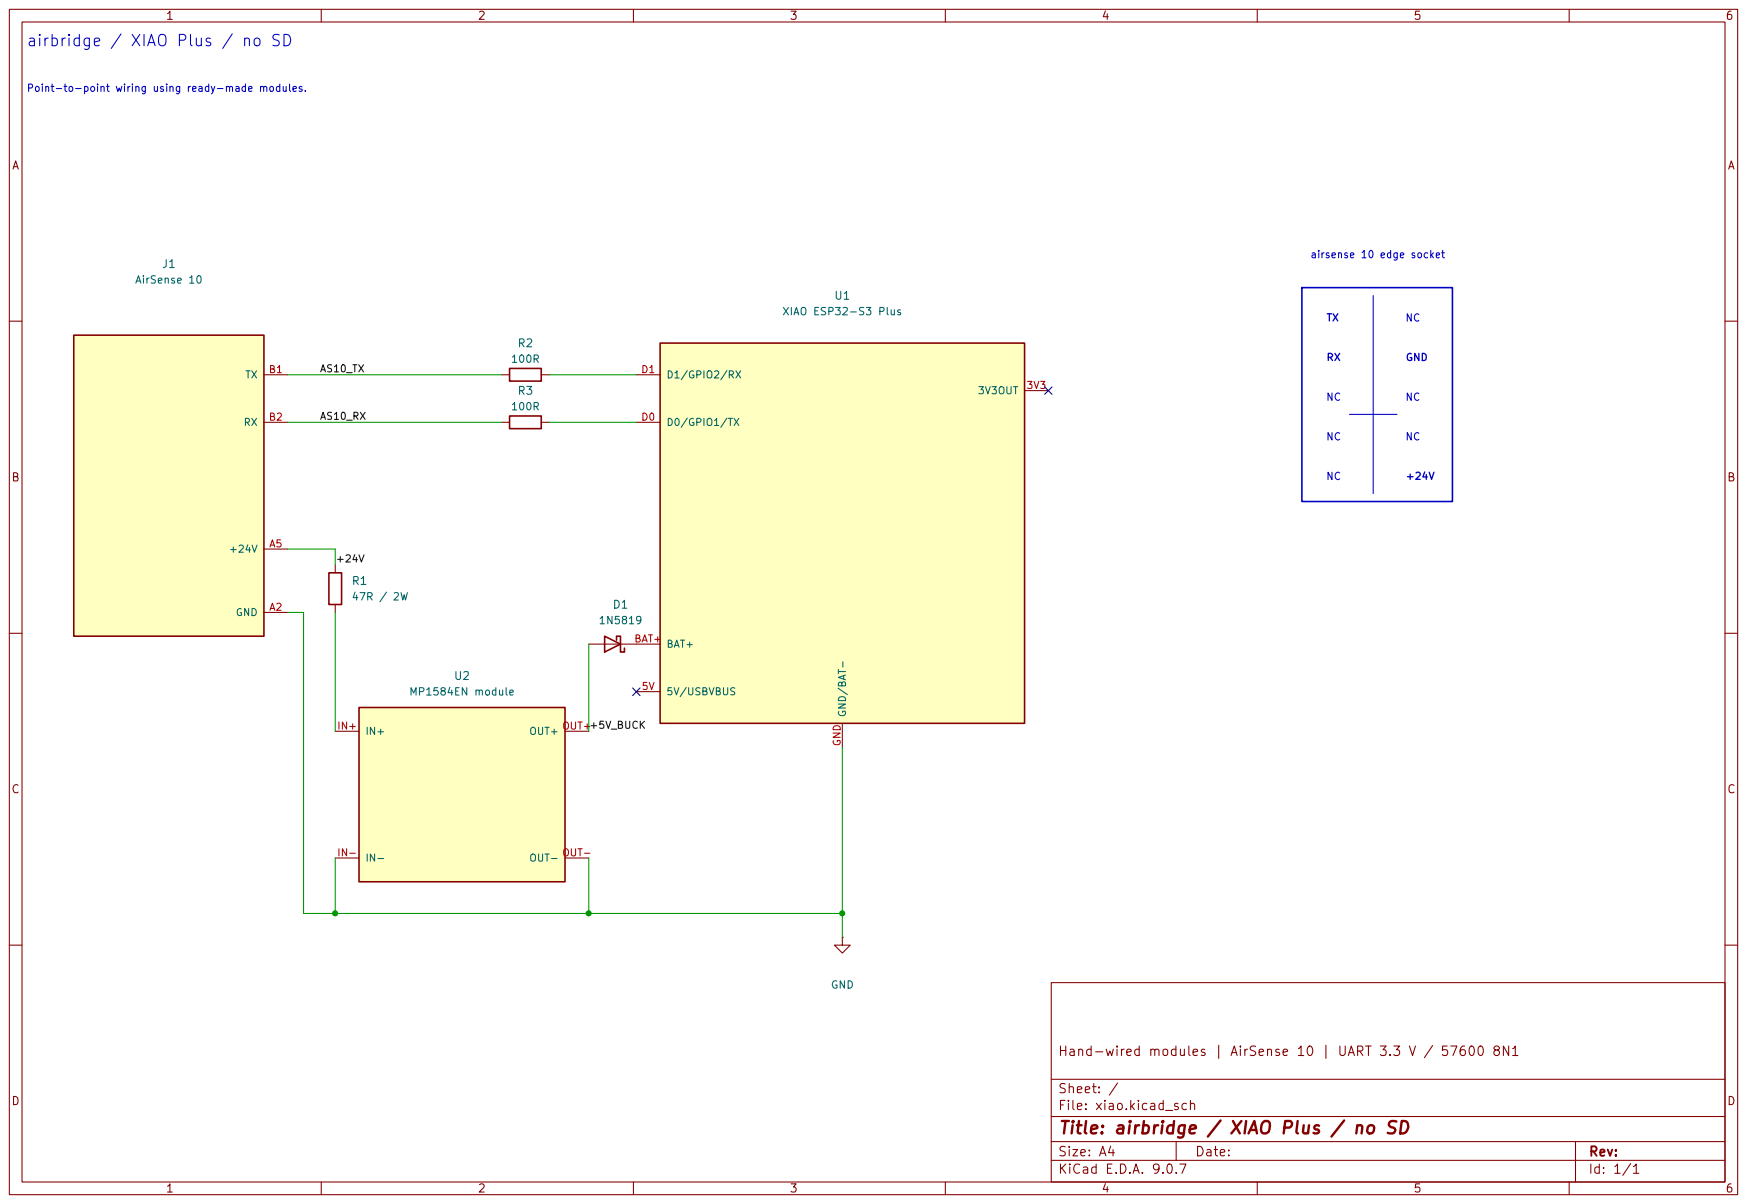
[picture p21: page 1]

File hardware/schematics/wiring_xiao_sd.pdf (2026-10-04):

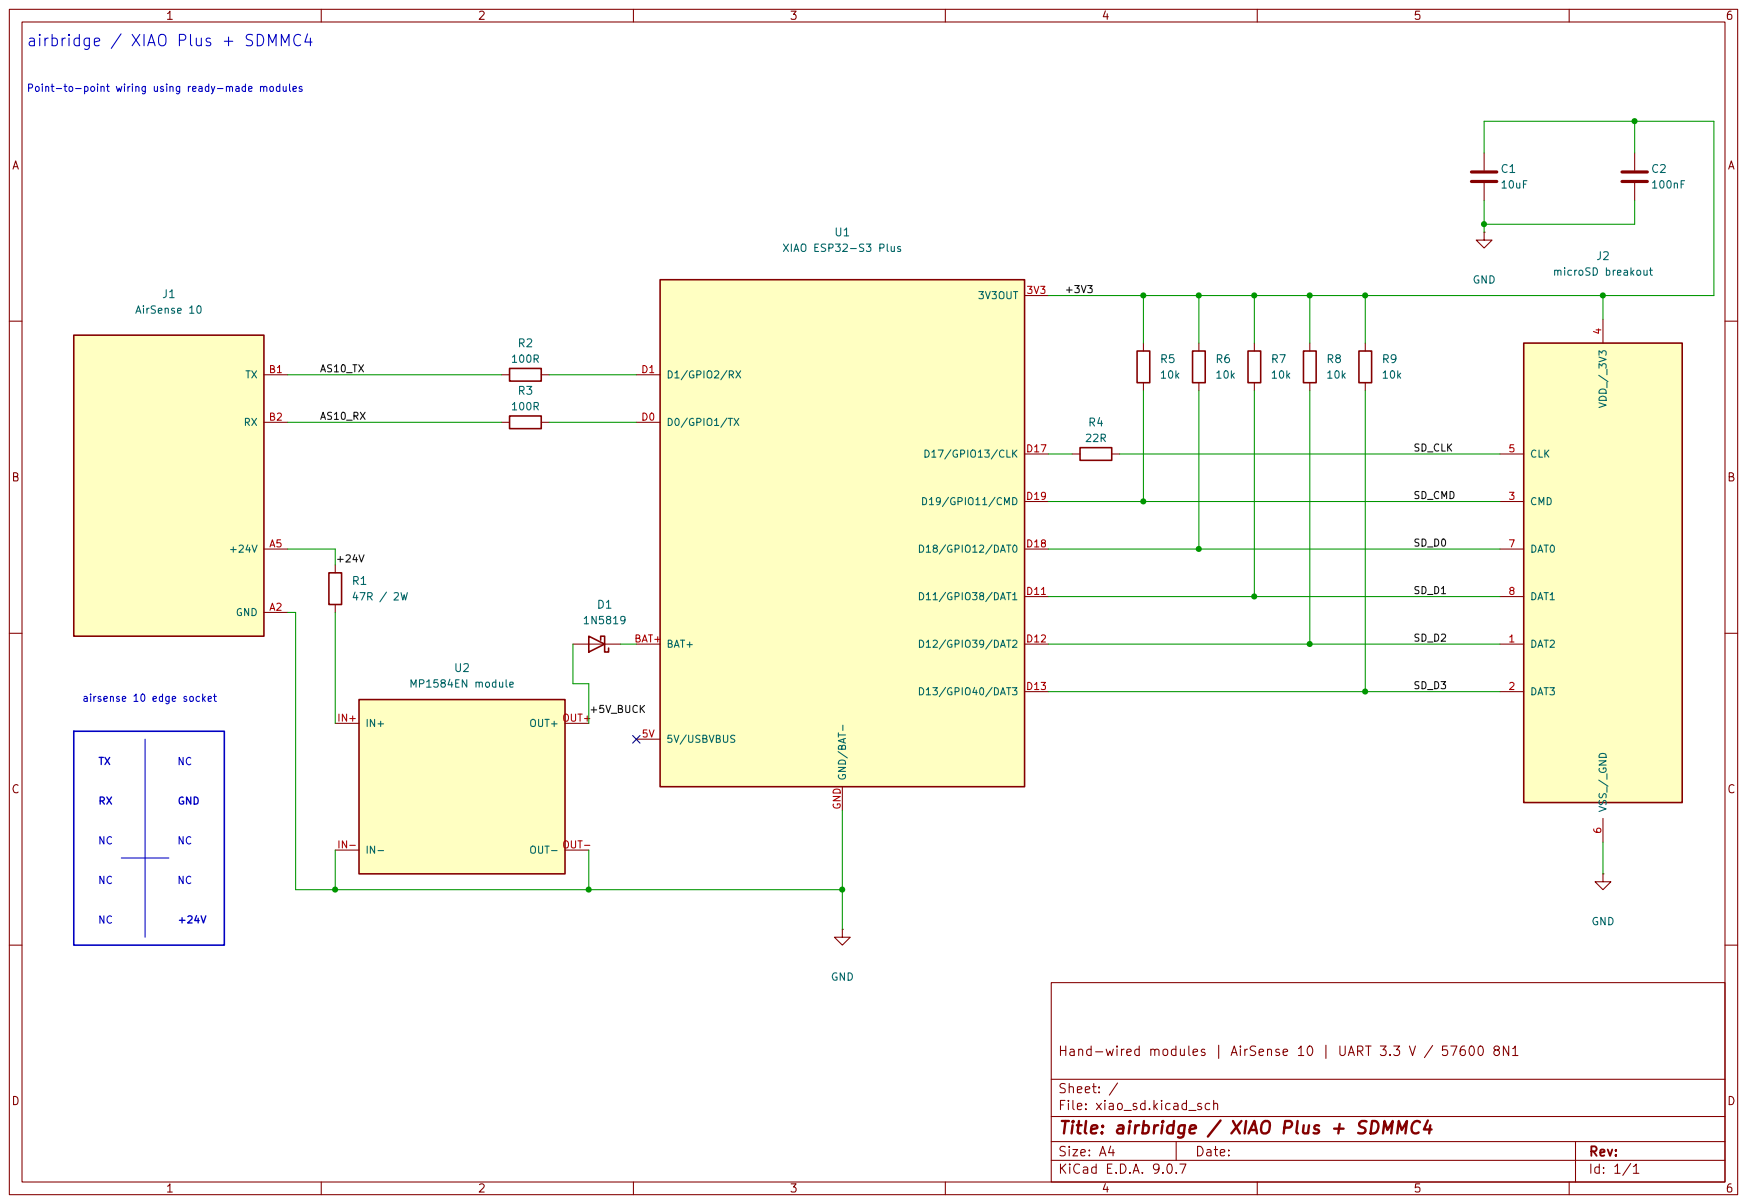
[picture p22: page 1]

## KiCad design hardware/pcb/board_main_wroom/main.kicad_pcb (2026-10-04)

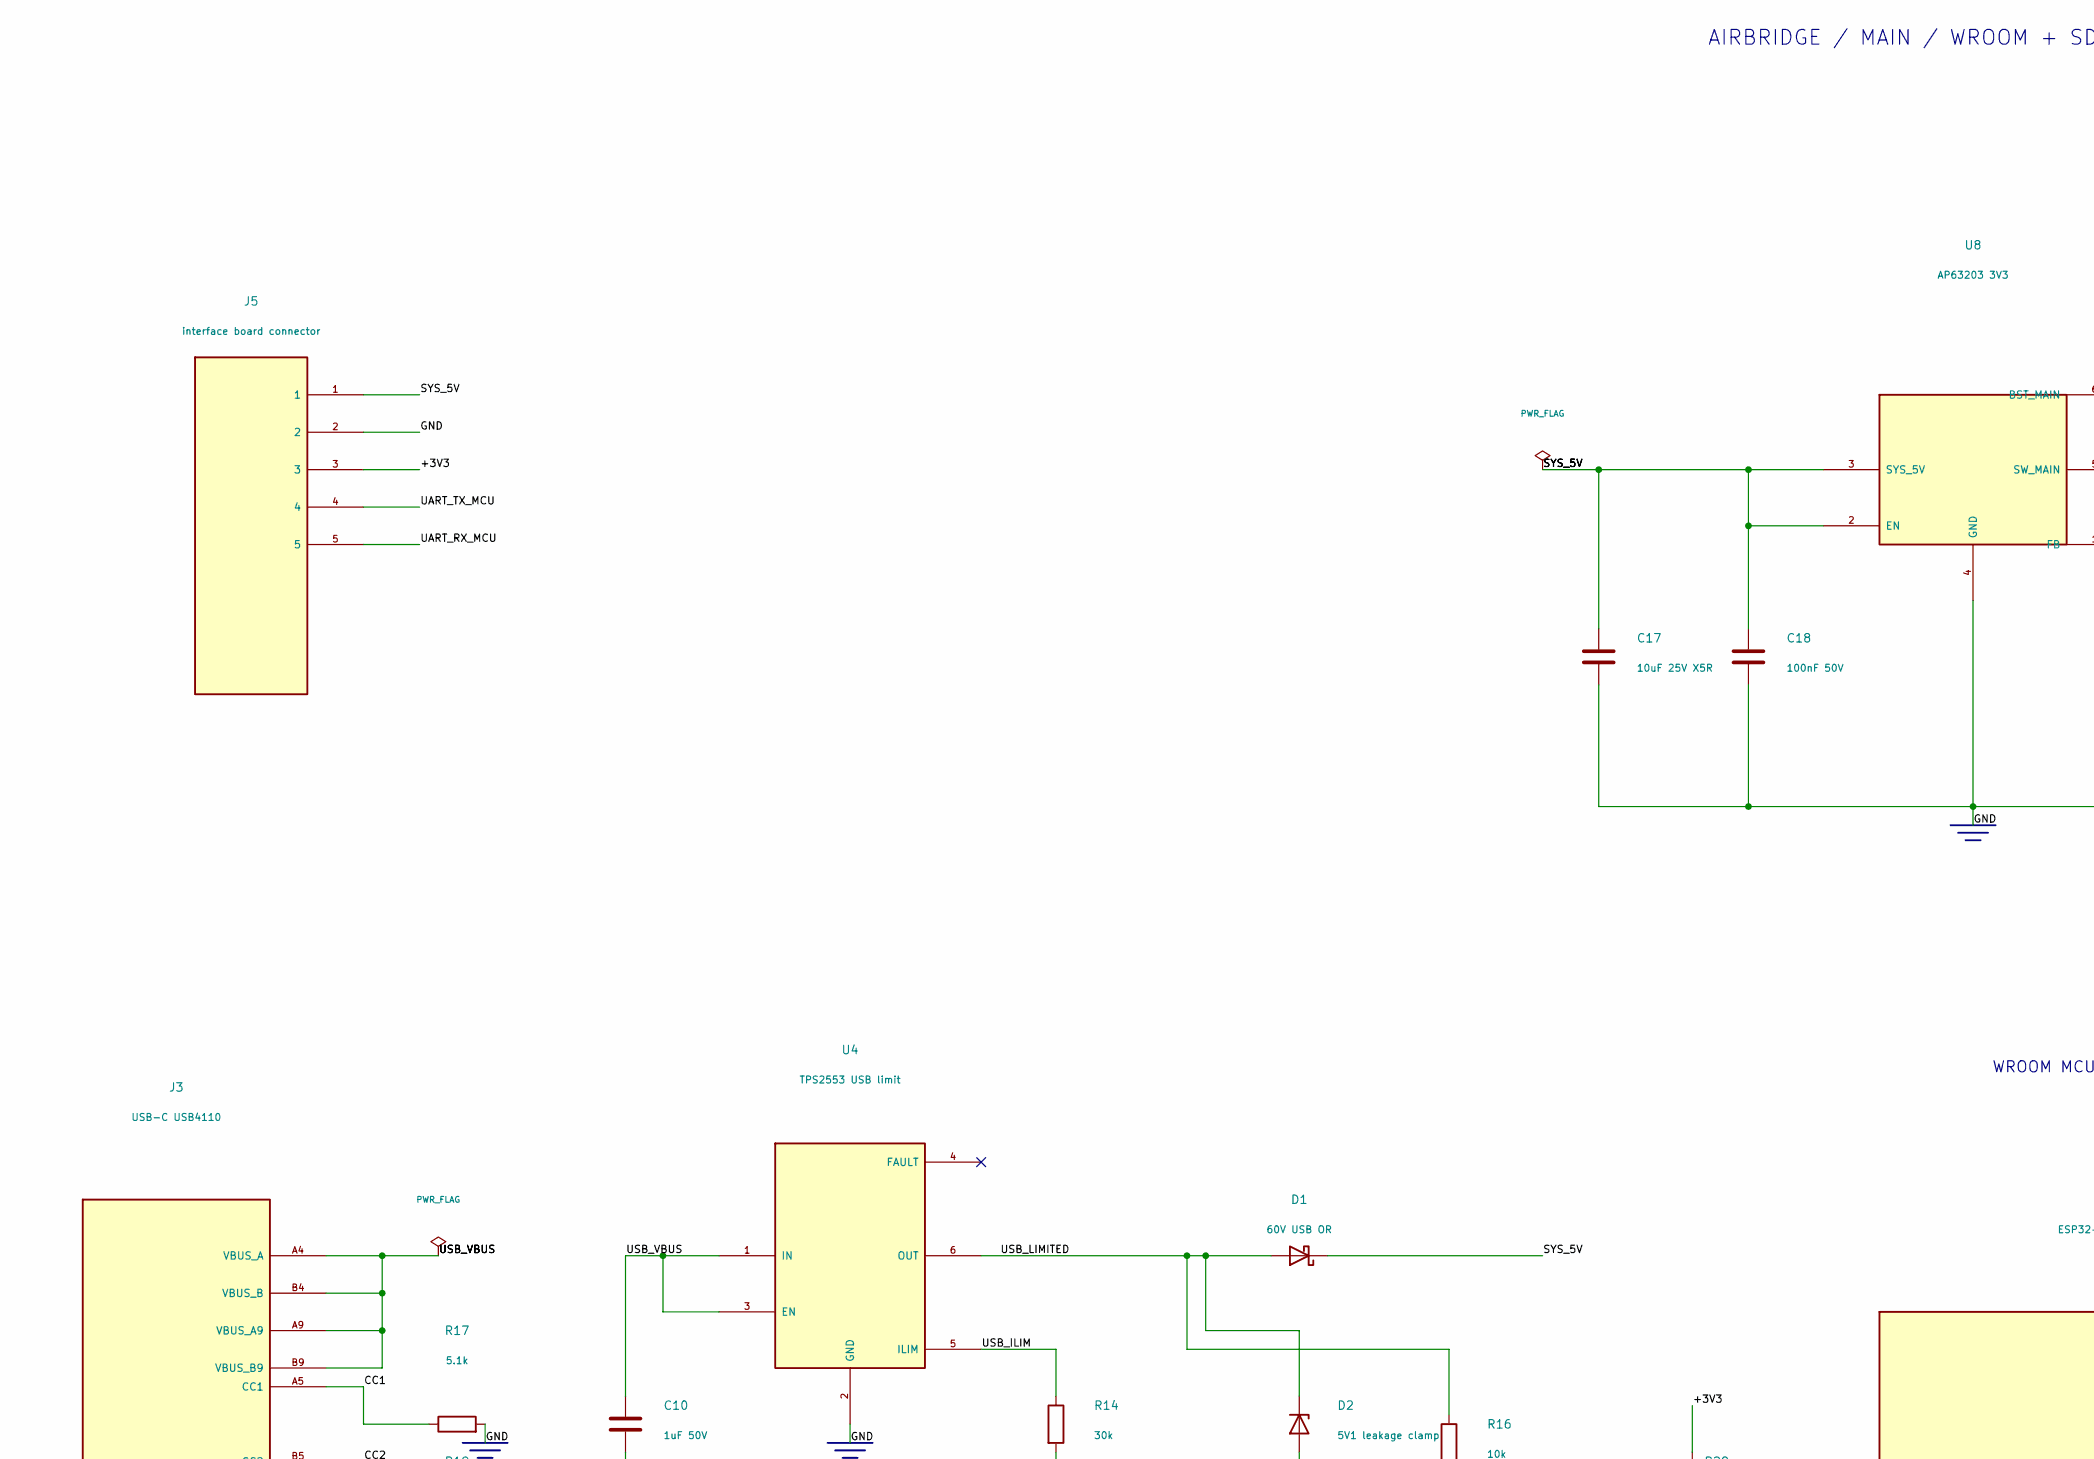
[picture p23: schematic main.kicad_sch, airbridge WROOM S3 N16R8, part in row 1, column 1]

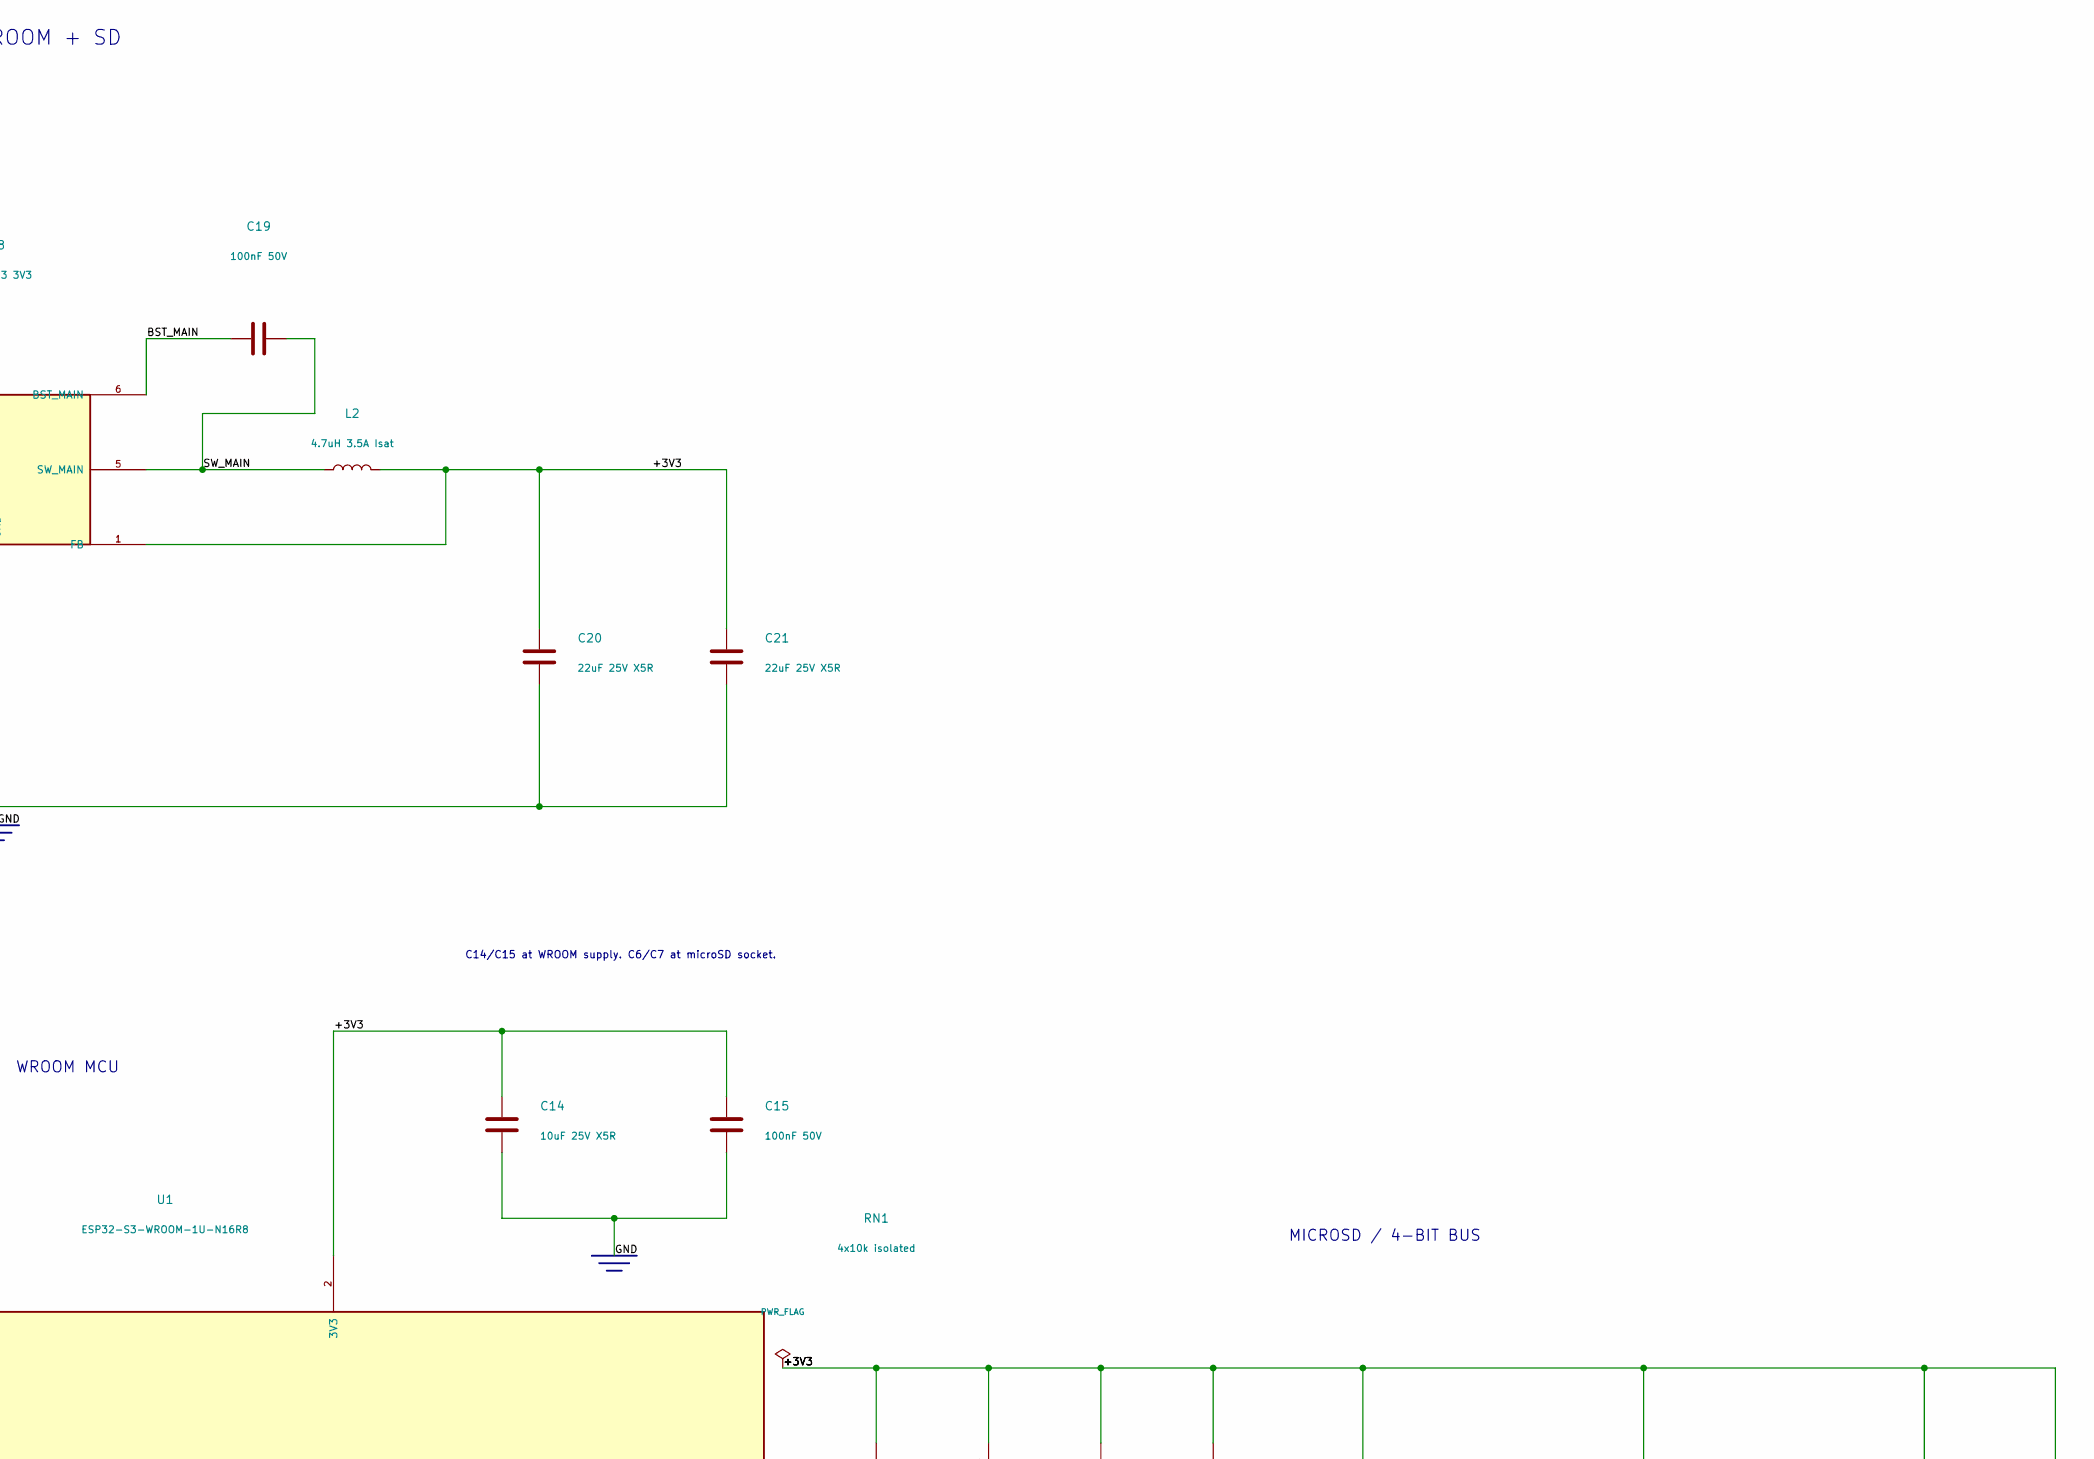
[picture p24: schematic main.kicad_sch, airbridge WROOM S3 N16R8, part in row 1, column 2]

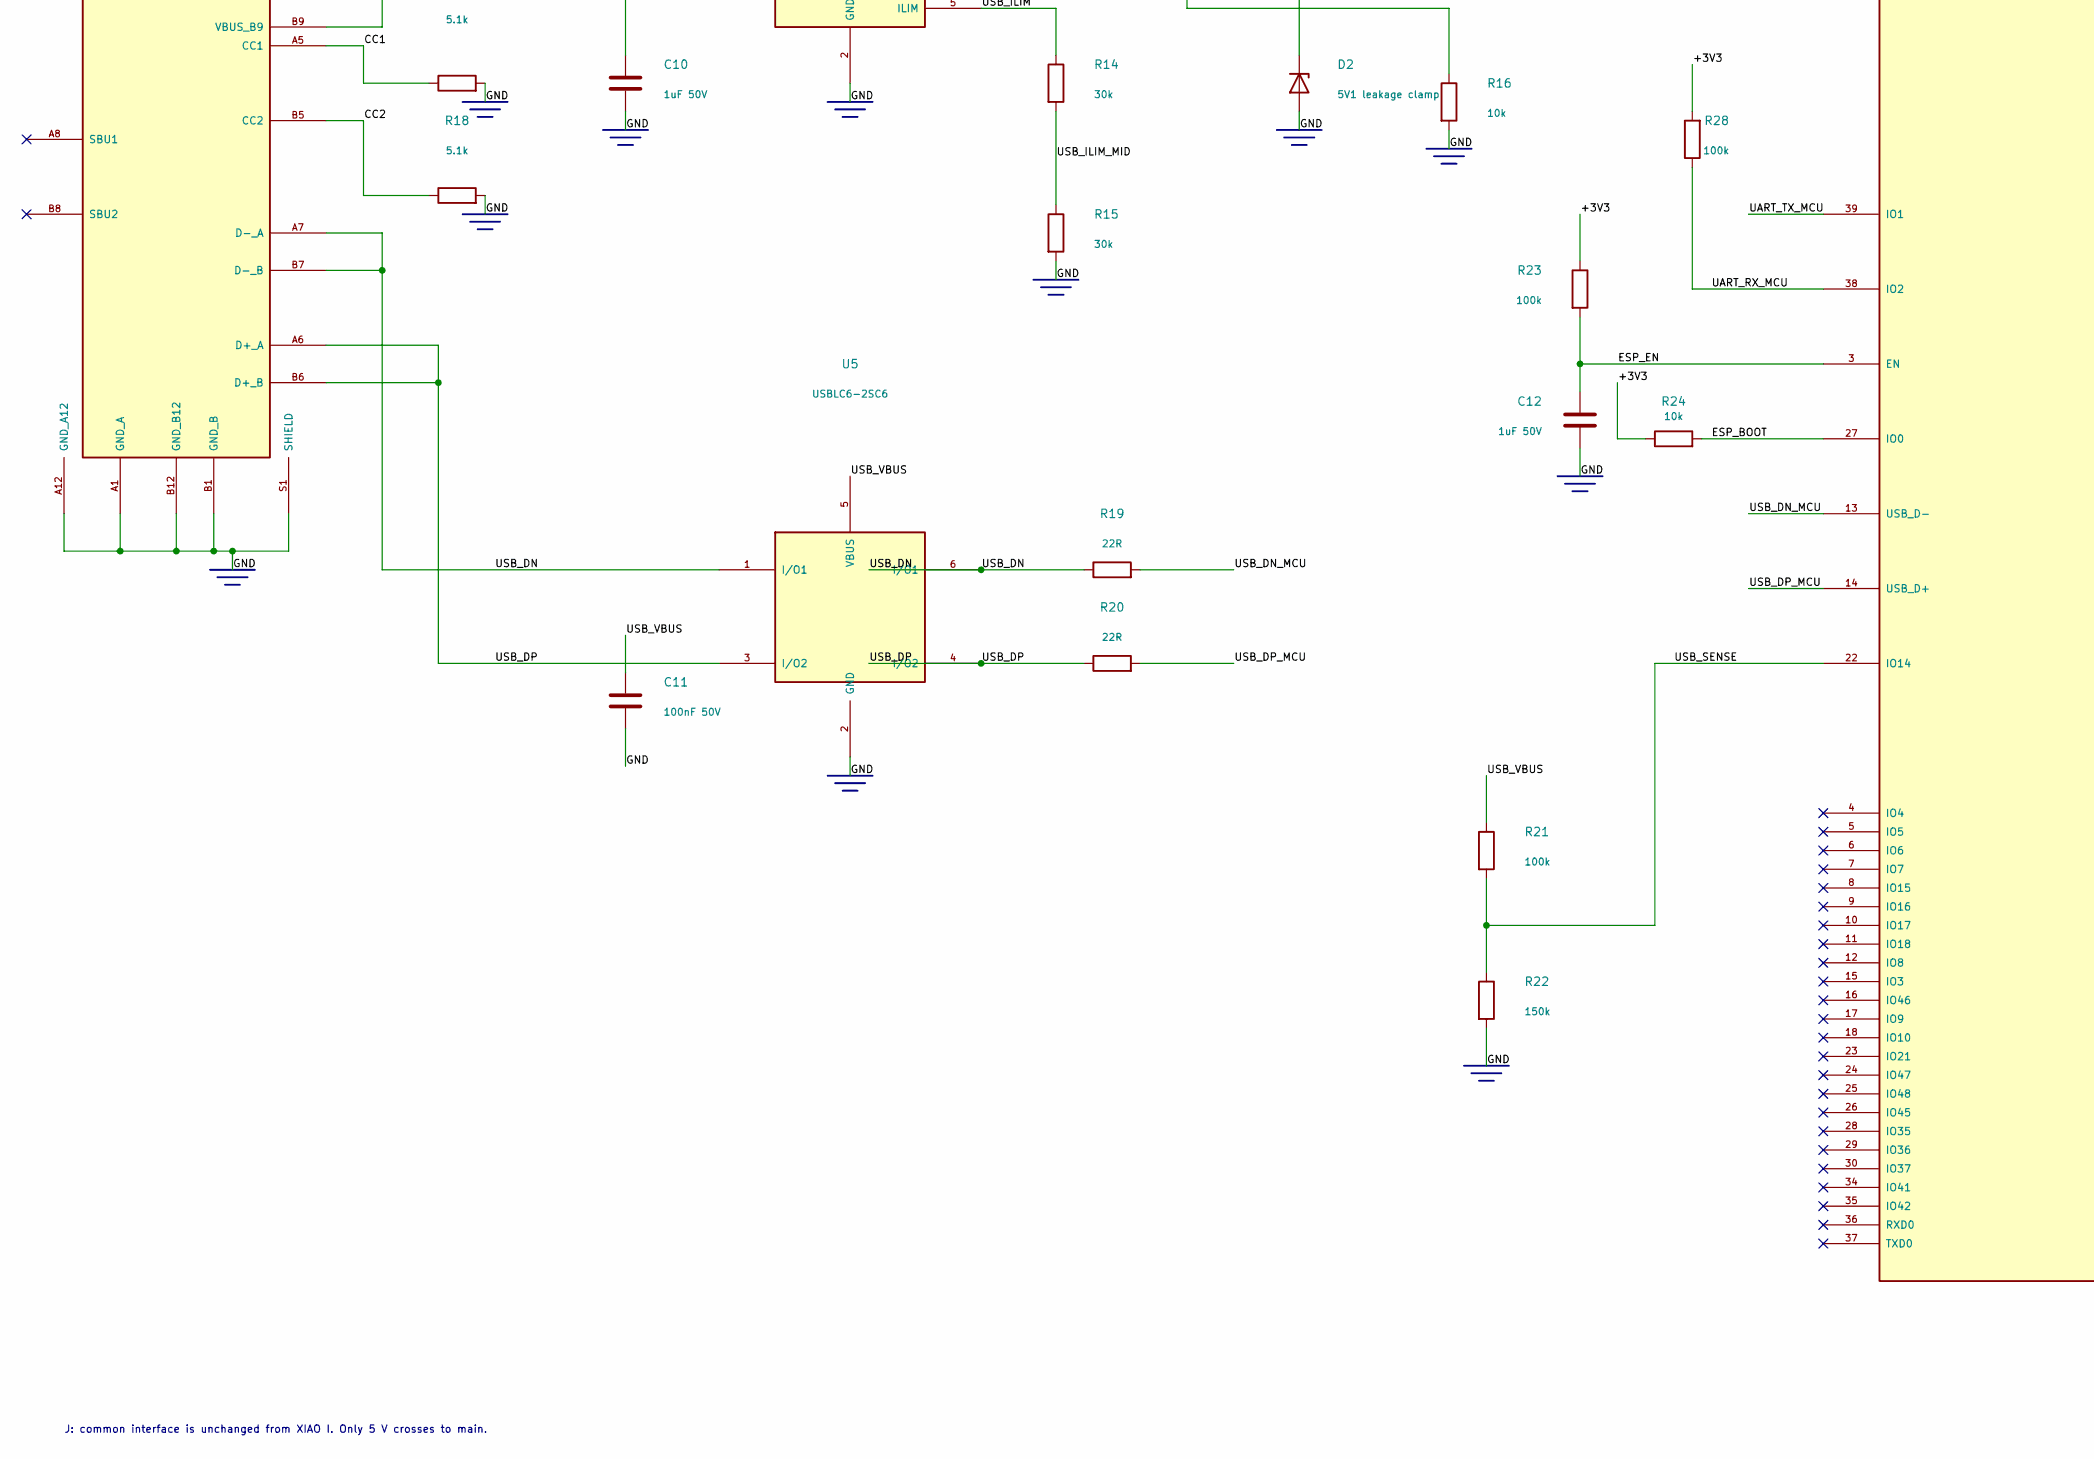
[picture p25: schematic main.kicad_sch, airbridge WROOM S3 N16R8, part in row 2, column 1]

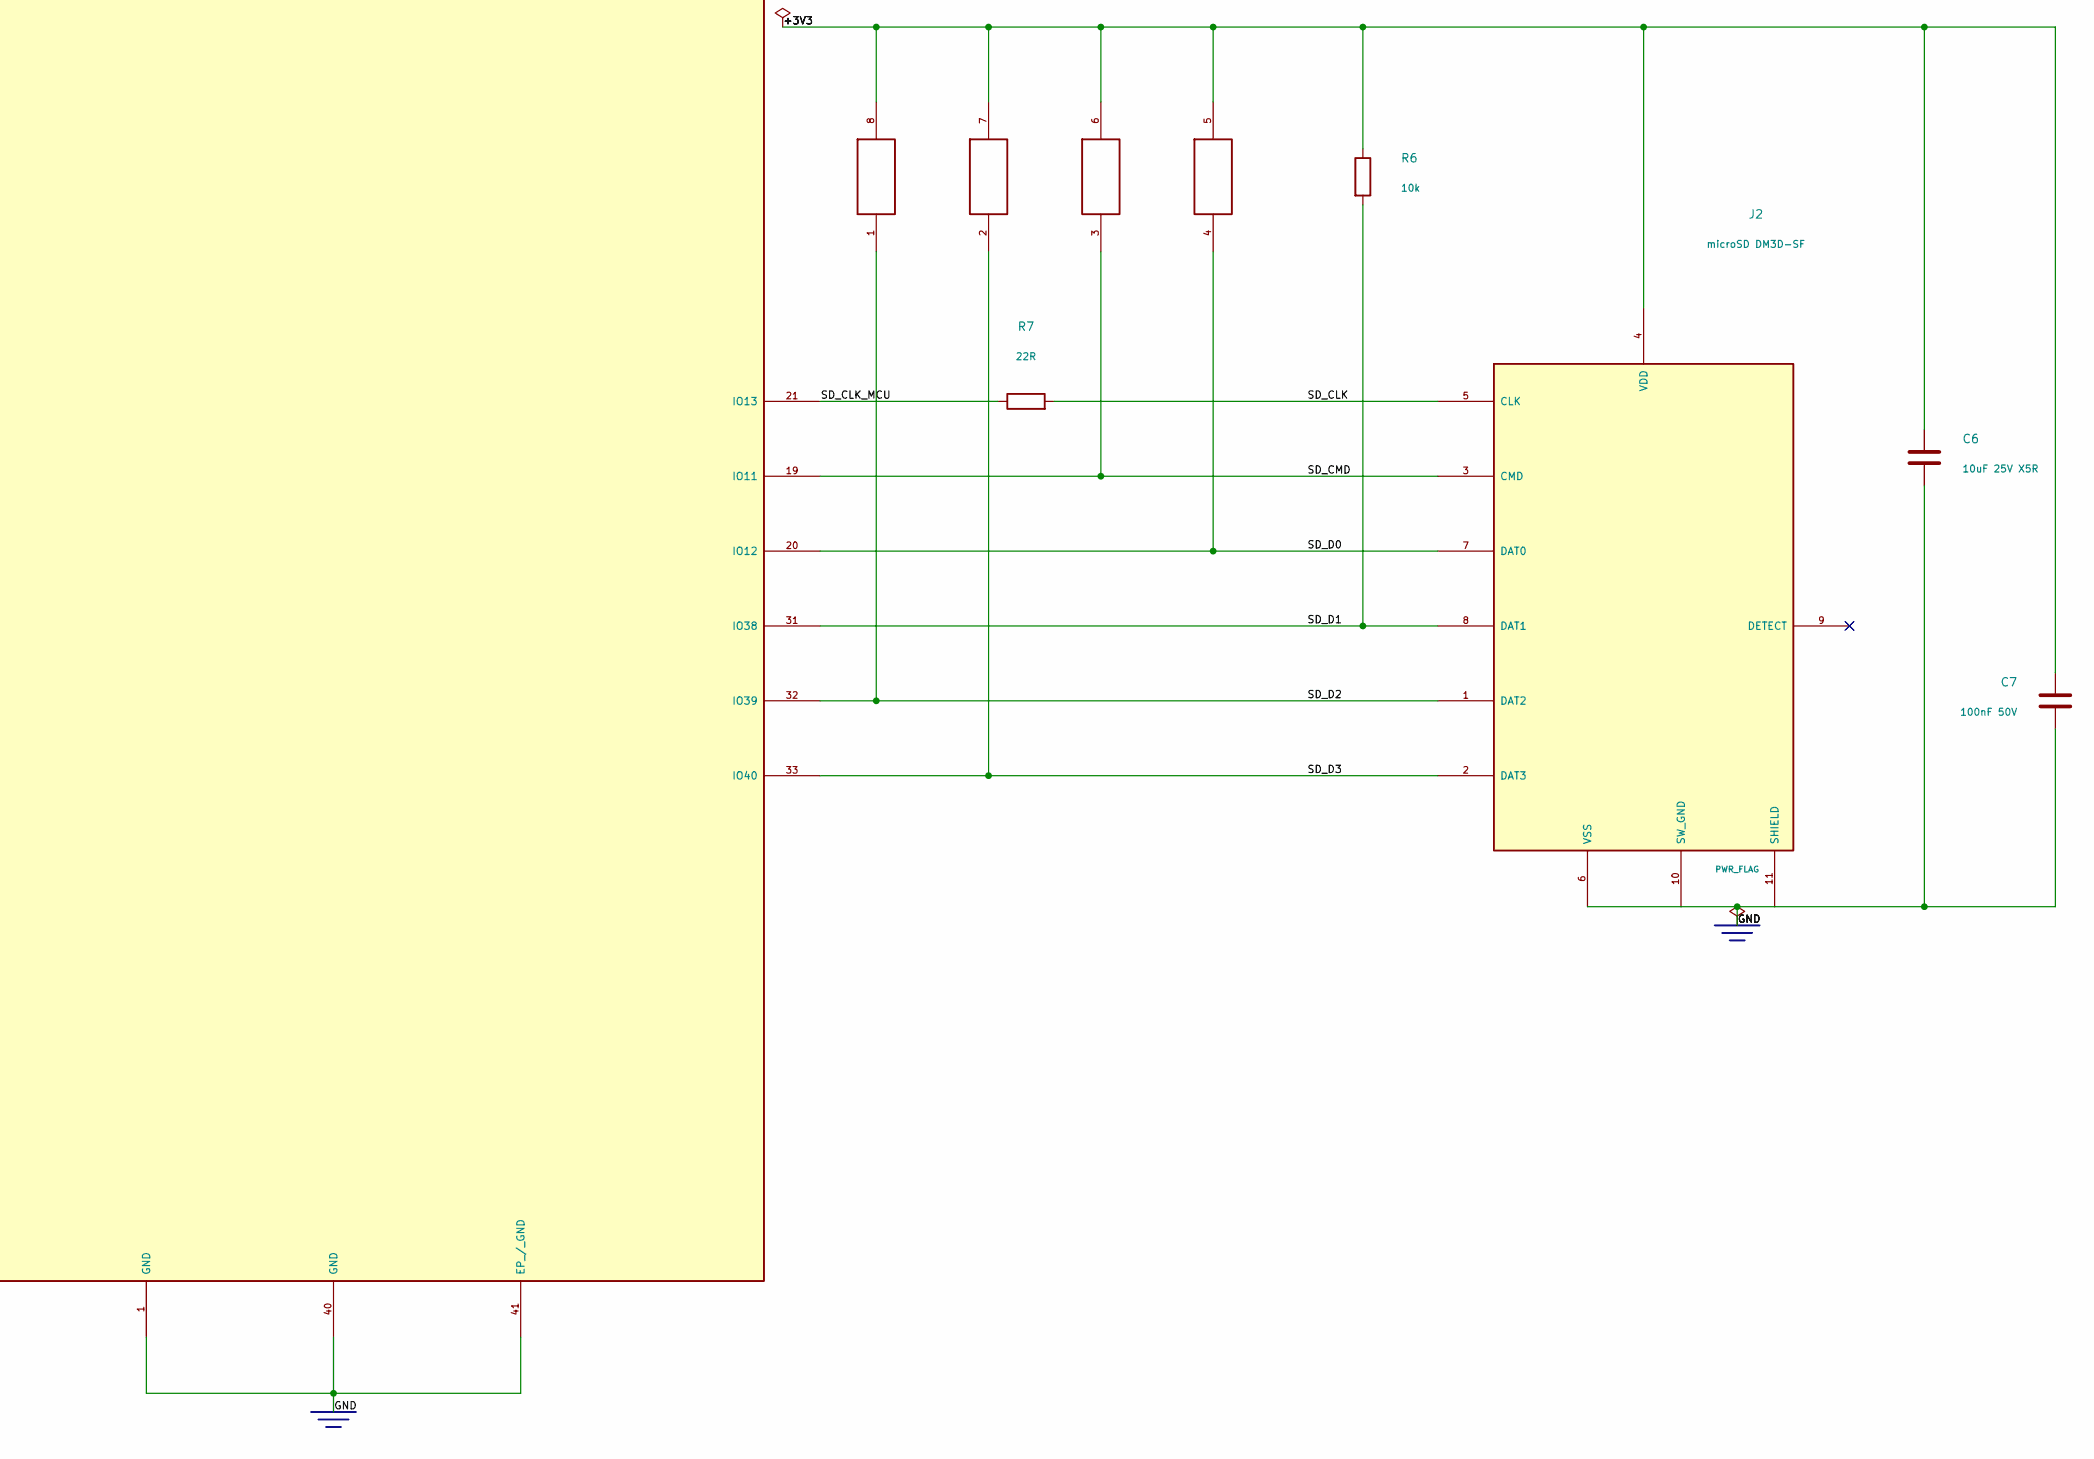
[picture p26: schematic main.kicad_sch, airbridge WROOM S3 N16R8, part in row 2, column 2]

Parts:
C6, C14, C17: 10uF 25V X5R; C_0805_2012Metric; MPN CL21A106KAYNNNE; LCSC C15850
C7, C11, C15, C18, C19: 100nF 50V; C_0603_1608Metric; MPN CC0603KRX7R9BB104; LCSC C14663
C10, C12: 1uF 50V; C_0603_1608Metric; MPN CL10A105KB8NNNC; LCSC C15849
C20, C21: 22uF 25V X5R; C_0805_2012Metric; MPN CL21A226MAQNNNE; LCSC C45783
D1: 60V USB OR; D_SOD-123F; MPN PMEG6010CEH,115; LCSC C110797
D2: 5V1 leakage clamp; D_SOD-123; MPN BZT52C5V1; LCSC C699211
J2: microSD DM3D-SF; microSD_HC_Hirose_DM3D-SF; MPN DM3D-SF; LCSC C719027
J3: USB-C USB4110; USB_C_Receptacle_GCT_USB4110; MPN USB4110-GF-A; LCSC C5143397
J5: interface board connector; SolderPins_1x05_P1.27mm
L2: 4.7uH 3.5A Isat; L_SRP4020TA; MPN SRP4020TA-4R7M; LCSC C2041623
R6, R16, R24: 10k; R_0603_1608Metric; MPN 0603WAF1002T5E; LCSC C25804
R7, R19, R20: 22R; R_0603_1608Metric; MPN 0603WAF220JT5E; LCSC C23345
R14, R15: 30k; R_0603_1608Metric; MPN 0603WAF3002T5E; LCSC C22984
R17, R18: 5.1k; R_0603_1608Metric; MPN 0603WAF5101T5E; LCSC C23186
R21, R23, R28: 100k; R_0603_1608Metric; MPN 0603WAF1003T5E; LCSC C25803
R22: 150k; R_0603_1608Metric; MPN 0603WAF1503T5E; LCSC C22807
RN1: 4x10k isolated; R_Array_Convex_4x0603; MPN 4D03WGJ0103T5E; LCSC C29718
U1: ESP32-S3-WROOM-1U-N16R8; WROOM_1U_03mm_vias; MPN ESP32-S3-WROOM-1U-N16R8; LCSC C3013946
U4: TPS2553 USB limit; SOT-23-6; MPN TPS2553DBVR; LCSC C55266
U5: USBLC6-2SC6; SOT-23-6; MPN USBLC6-2SC6; LCSC C7519
U8: AP63203 3V3; SOT-23-6; MPN AP63203WU-7; LCSC C780769

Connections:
/+3V3: C6.1, C7.1, C14.1, C15.1, C20.1, C21.1, J2.4 (VDD), J5.3, L2.2, R6.1, R23.1, R24.1, R28.2, RN1.5, RN1.6, RN1.7, RN1.8, U1.2 (3V3), U8.1 (FB)
/BST_MAIN: C19.1, U8.6 (BST_MAIN)
/CC1: J3.A5 (CC1), R17.1
/CC2: J3.B5 (CC2), R18.1
/ESP_BOOT: R24.2, U1.27 (IO0)
/ESP_EN: C12.1, R23.2, U1.3 (EN)
/GND: C6.2, C7.2, C10.2, C11.2, C12.2, C14.2, C15.2, C17.2, C18.2, C20.2, C21.2, D2.2 (A), J2.6 (VSS), J2.10 (SW_GND), J2.11 (SHIELD), J3.A1 (GND_A), J3.A12 (GND_A12), J3.B1 (GND_B), J3.B12 (GND_B12), J3.S1 (SHIELD), J5.2, R15.2, R16.2, R17.2, R18.2, R22.2, U1.1 (GND), U1.40 (GND), U1.41 (EP_/_GND), U4.2 (GND), U5.2 (GND), U8.4 (GND)
/SD_CLK: J2.5 (CLK), R7.2
/SD_CLK_MCU: R7.1, U1.21 (IO13)
/SD_CMD: J2.3 (CMD), RN1.3, U1.19 (IO11)
/SD_D0: J2.7 (DAT0), RN1.4, U1.20 (IO12)
/SD_D1: J2.8 (DAT1), R6.2, U1.31 (IO38)
/SD_D2: J2.1 (DAT2), RN1.1, U1.32 (IO39)
/SD_D3: J2.2 (DAT3), RN1.2, U1.33 (IO40)
/SW_MAIN: C19.2, L2.1, U8.5 (SW_MAIN)
/SYS_5V: C17.1, C18.1, D1.1 (K), J5.1, U8.2 (EN), U8.3 (SYS_5V)
/UART_RX_MCU: J5.5, R28.1, U1.38 (IO2)
/UART_TX_MCU: J5.4, U1.39 (IO1)
/USB_DN: J3.A7 (D-_A), J3.B7 (D-_B), R19.1, U5.1 (I/O1), U5.6 (I/O1)
/USB_DN_MCU: R19.2, U1.13 (USB_D-)
/USB_DP: J3.A6 (D+_A), J3.B6 (D+_B), R20.1, U5.3 (I/O2), U5.4 (I/O2)
/USB_DP_MCU: R20.2, U1.14 (USB_D+)
/USB_ILIM: R14.1, U4.5 (ILIM)
/USB_ILIM_MID: R14.2, R15.1
/USB_LIMITED: D1.2 (A), D2.1 (K), R16.1, U4.6 (OUT)
/USB_SENSE: R21.2, R22.1, U1.22 (IO14)
/USB_VBUS: C10.1, C11.1, J3.A4 (VBUS_A), J3.A9 (VBUS_A9), J3.B4 (VBUS_B), J3.B9 (VBUS_B9), R21.1, U4.1 (IN), U4.3 (EN), U5.5 (VBUS)

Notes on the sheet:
J: common interface is unchanged from XIAO I. Only 5 V crosses to main.
C14/C15 at WROOM supply. C6/C7 at microSD socket.
WROOM MCU
MICROSD / 4-BIT BUS
AIRBRIDGE / MAIN / WROOM + SD

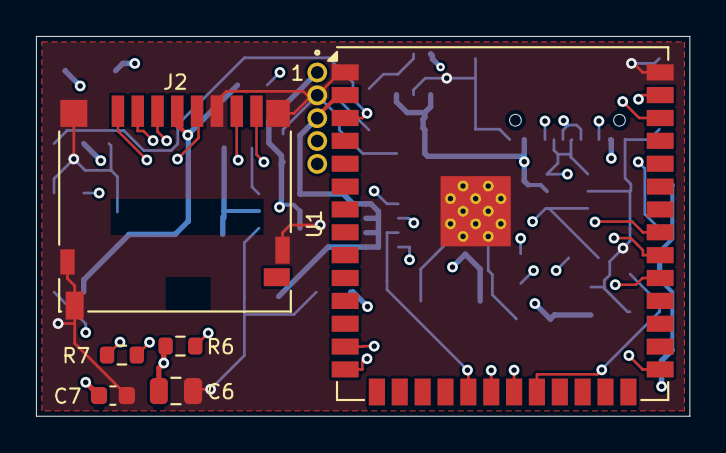
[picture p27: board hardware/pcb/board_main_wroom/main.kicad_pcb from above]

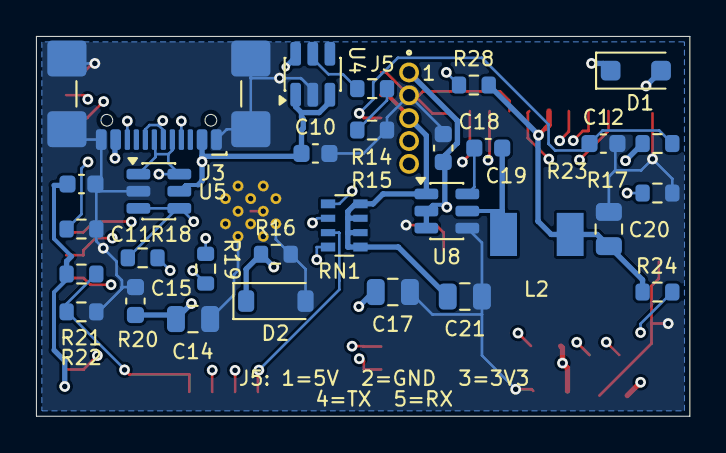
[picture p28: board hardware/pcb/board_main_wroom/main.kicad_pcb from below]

Board: 4 copper layers, 36.3 x 21.1 mm, 37 parts (30 on the bottom side), 27 nets.

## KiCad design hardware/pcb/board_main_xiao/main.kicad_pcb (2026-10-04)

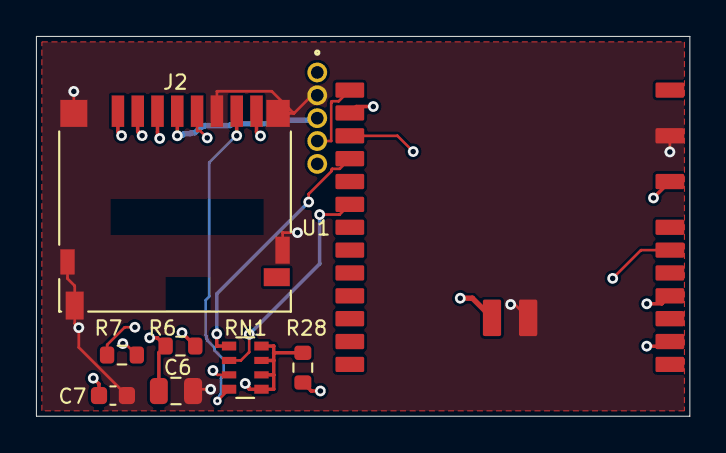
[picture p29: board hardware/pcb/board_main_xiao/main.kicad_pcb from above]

Board: 4 copper layers, 36.3 x 21.1 mm, 9 parts (0 on the bottom side), 12 nets.

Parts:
C6: 10uF 25V X5R; C_0805_2012Metric
C7: 100nF 50V; C_0603_1608Metric
J2: microSD DM3D-SF; microSD_HC_Hirose_DM3D-SF
J5: 5 soldered pins / 1.27mm; SolderPins_1x05_P1.27mm
R6: 10k; R_0603_1608Metric
R7: 22R; R_0603_1608Metric
R28: 100k; R_0603_1608Metric
RN1: 4x10k isolated; R_Array_Convex_4x0603
U1: XIAO ESP32S3 Plus; XIAO_Plus_BAT_25P

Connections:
/+3V3: C6.1, C7.1, J2.4, J5.3, R6.1, R28.2, RN1.5, RN1.6, RN1.7, RN1.8, U1.12
/GND: C6.2, C7.2, J2.6, J2.10, J2.11, J5.2, U1.13, U1.33
/SD_CLK: J2.5, R7.2
/SD_CLK_MCU: R7.1, U1.23
/SD_CMD: J2.3, RN1.3, U1.21
/SD_D0: J2.7, RN1.4, U1.22
/SD_D1: J2.8, R6.2, U1.15
/SD_D2: J2.1, RN1.1, U1.16
/SD_D3: J2.2, RN1.2, U1.17
/SYS_5V: J5.1, U1.32
/UART_RX_MCU: J5.5, R28.1, U1.2
/UART_TX_MCU: J5.4, U1.1

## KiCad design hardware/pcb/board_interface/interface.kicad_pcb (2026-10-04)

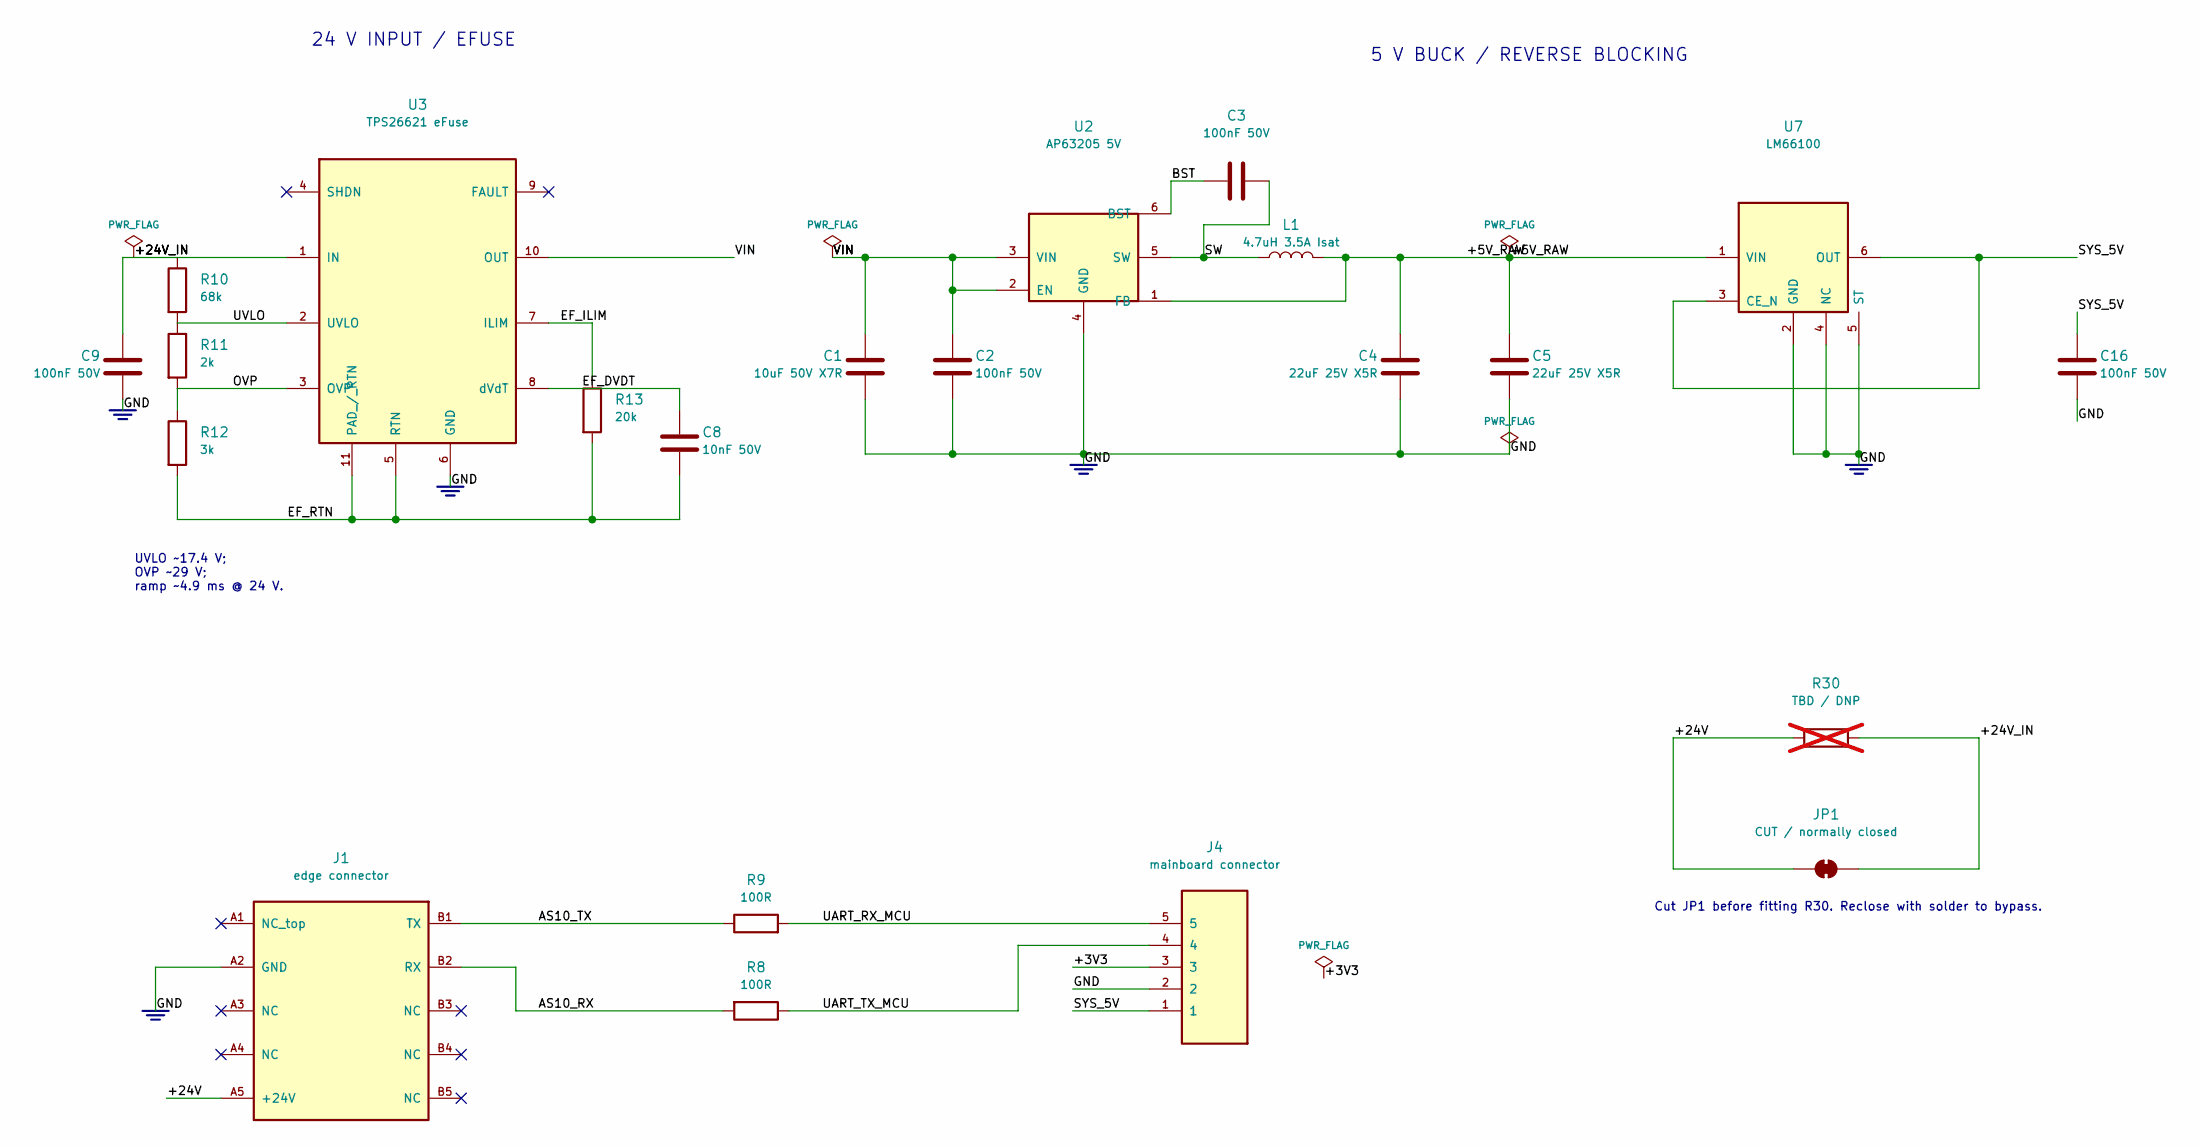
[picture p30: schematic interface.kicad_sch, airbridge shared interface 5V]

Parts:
C1: 10uF 50V X7R; C_1210_3225Metric; MPN CL32B106KBJNNNE; LCSC C138687
C2, C3, C9, C16: 100nF 50V; C_0603_1608Metric; MPN CC0603KRX7R9BB104; LCSC C14663
C4, C5: 22uF 25V X5R; C_0805_2012Metric; MPN CL21A226MAQNNNE; LCSC C45783
C8: 10nF 50V; C_0603_1608Metric; MPN 0603B103K500NT; LCSC C57112
J1: edge connector; AirSense10_Edge; MPN PCB fingers
J4: mainboard connector; SolderPins_1x05_P1.27mm
JP1: CUT / normally closed; Input_CutBridge
L1: 4.7uH 3.5A Isat; L_SRP4020TA; MPN SRP4020TA-4R7M; LCSC C2041623
R8, R9: 100R; R_0603_1608Metric; MPN 0603WAF1000T5E; LCSC C22775
R10: 68k; R_0603_1608Metric; MPN 0603WAF6802T5E; LCSC C23231
R11: 2k; R_0603_1608Metric; MPN 0603WAF2001T5E; LCSC C22975
R12: 3k; R_0603_1608Metric; MPN 0603WAF3001T5E; LCSC C4211
R13: 20k; R_0603_1608Metric; MPN 0603WAF2002T5E; LCSC C4184
R30: TBD / DNP; R_1206_3216Metric; not fitted
U2: AP63205 5V; SOT-23-6; MPN AP63205WU-7; LCSC C2071056
U3: TPS26621 eFuse; VSON-10-1EP_3x3mm_P0.5mm_EP1.65x2.4mm; MPN TPS26621DRCR; LCSC C1848341
U7: LM66100; SOT-363_SC-70-6; MPN LM66100DCKR; LCSC C2869734

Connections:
/+3V3: J4.3
/+5V_RAW: C4.1, C5.1, L1.2, U2.1 (FB), U7.1 (VIN)
/+24V: J1.A5 (+24V), JP1.1 (A), R30.1
/+24V_IN: C9.1, JP1.2 (B), R10.1, R30.2, U3.1 (IN)
/AS10_RX: J1.B2 (RX), R8.2
/AS10_TX: J1.B1 (TX), R9.1
/BST: C3.1, U2.6 (BST)
/EF_DVDT: C8.1, U3.8 (dVdT)
/EF_ILIM: R13.1, U3.7 (ILIM)
/EF_RTN: C8.2, R12.2, R13.2, U3.5 (RTN), U3.11 (PAD_/_RTN)
/GND: C1.2, C2.2, C4.2, C5.2, C9.2, C16.2, J1.A2 (GND), J4.2, U2.4 (GND), U3.6 (GND), U7.2 (GND), U7.4 (NC), U7.5 (ST)
/OVP: R11.2, R12.1, U3.3 (OVP)
/SW: C3.2, L1.1, U2.5 (SW)
/SYS_5V: C16.1, J4.1, U7.3 (CE_N), U7.6 (OUT)
/UART_RX_MCU: J4.5, R9.2
/UART_TX_MCU: J4.4, R8.1
/UVLO: R10.2, R11.1, U3.2 (UVLO)
/VIN: C1.1, C2.1, U2.2 (EN), U2.3 (VIN), U3.10 (OUT)

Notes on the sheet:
Cut JP1 before fitting R30. Reclose with solder to bypass.
24 V INPUT / EFUSE
5 V BUCK / REVERSE BLOCKING
UVLO ~17.4 V; OVP ~29 V; ramp ~4.9 ms @ 24 V.

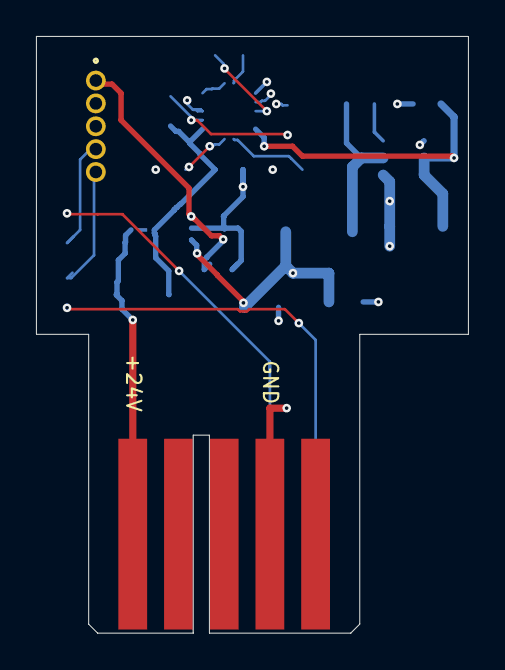
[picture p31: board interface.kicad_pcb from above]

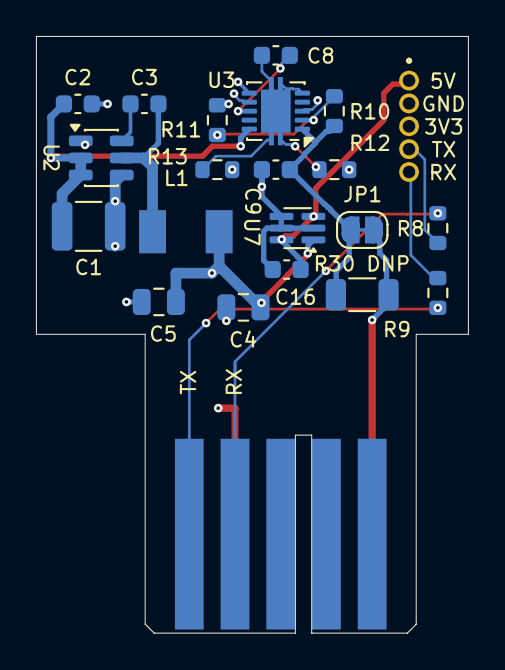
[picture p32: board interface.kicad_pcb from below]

Board: 4 copper layers, 24.0 x 33.2 mm, 22 parts (20 on the bottom side), 17 nets.

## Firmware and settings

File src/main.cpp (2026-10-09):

#include <Arduino.h>
#include "app_config.h"
#include "build_info.h"
#include "debug_log.h"
#include "crash_diagnostics.h"
#include "uart_arbiter.h"
#include "tcp_bridge.h"
#include "wifi_setup.h"
#include "oxi_ble.h"
#include "oxi_udp.h"
#include "oxi_arbiter.h"
#include "airbridge_ota.h"
#include "factory_reset.h"
#include "tls_memory.h"
#include "web_ui.h"
#include "qframe.h"
#include "network_hints.h"
#include "live_stream.h"
#include "air10_stream.h"
#include "live_tce.h"
#include "live_web_consumer.h"
#include "sd_storage.h"
#include "edf_recorder.h"
#include "export_sync.h"
#include "custom_settings.h"
#include "clinical_jobs.h"
#include "sleep_report.h"
#include "airsense_state.h"
#include "air10_clock.h"
#include "board.h"
#include "status_screen.h"
#if defined(AB_BOARD_WROOM_S3)
#include "hal/usb_serial_jtag_ll.h"

// Rev D senses VBUS through 100k/150k. Disconnect the self-powered USB
// peripheral when the host removes VBUS; power conversion is independent.
static void IRAM_ATTR usb_vbus_changed() {
    usb_serial_jtag_ll_phy_enable_pad(digitalRead(14) == HIGH);
}
#endif

extern void dispatch_command(const char *line, String &response);

#define SERIAL_LINE_MAX 256
static char serial_line[SERIAL_LINE_MAX];
static int serial_pos = 0;

static void serial_poll() {
    while (Serial.available()) {
        char c = Serial.read();

        if (c == '\n' || c == '\r') {
            if (serial_pos > 0) {
                serial_line[serial_pos] = '\0';

                if (serial_line[0] == '$') {
                    // Internal command
                    String response;
                    dispatch_command(serial_line + 1, response);
                    if (response.length() > 0) Log::write_crlf(Serial, response);
                } else {
                    // Q-frame
                    char resp_buf[512] = {};
                    uint16_t resp_len = sizeof(resp_buf);
                    bool ok = Arbiter::send_cmd(serial_line, CMD_SRC_INTERNAL,
                                                CMD_PRIO_NORMAL, resp_buf,
                                                &resp_len, 2000);
                    if (ok) {
                        Serial.println(resp_buf);
                    } else {
                        Serial.println("ERR:TIMEOUT");
                    }
                }
                serial_pos = 0;
            }
        } else if (c == '\b' || c == '\x7f') {
            if (serial_pos > 0) --serial_pos;
        } else if (serial_pos < SERIAL_LINE_MAX - 1) {
            serial_line[serial_pos++] = c;
        }
    }
}

void setup() {
    Arbiter::prepare_tx(PIN_AS10_TX);

#ifdef AB_LCD_BACKLIGHT_GPIO
    // Keep the unused local display dark, including boards with a BL pull-up.
    pinMode(AB_LCD_BACKLIGHT_GPIO, OUTPUT);
    digitalWrite(AB_LCD_BACKLIGHT_GPIO, LOW);
#endif
#if AB_POWER_HOLD_GPIO >= 0
    pinMode(AB_POWER_HOLD_GPIO, OUTPUT);      // keep battery path latched on
    digitalWrite(AB_POWER_HOLD_GPIO, HIGH);
#endif
#if AB_LCD_BL_GPIO >= 0
    pinMode(AB_LCD_BL_GPIO, OUTPUT);          // keep panel dark until it is initialized
    digitalWrite(AB_LCD_BL_GPIO, LOW);
#endif
#if AB_TOUCH_RST_GPIO >= 0
    pinMode(AB_TOUCH_RST_GPIO, OUTPUT);       // hold touch controller in reset,
    digitalWrite(AB_TOUCH_RST_GPIO, LOW);     // off the shared I2C bus
#endif

    Serial.begin(115200);
#if defined(AB_BOARD_WROOM_S3)
    pinMode(14, INPUT);
    attachInterrupt(digitalPinToInterrupt(14), usb_vbus_changed, CHANGE);
    usb_vbus_changed();
#endif
    delay(500);
    while (Serial.available()) Serial.read();  // flush boot garbage
    Log::init();
    if (!FactoryReset::run_pending_on_boot()) {
        for (;;) {
            Log::poll();
            delay(1000);
        }
    }

    if (!aircannect::TlsMemory::begin())
        Log::logf(CAT_GENERAL, LOG_ERROR, "[INIT] TLS allocator installation failed\n");

    Log::boot();
    Log::logf(CAT_GENERAL, LOG_DEBUG, "Chip: %s, Heap: %d bytes\n", ESP.getChipModel(), ESP.getFreeHeap());

    Config::init();
    // NetworkHints must come up before Config::load runs the wnet migration,
    // because that step calls NetworkHints::upsert with legacy hint values.
    NetworkHints::init();
    Config::load();
    CrashDiagnostics::init();
    Log::logf(CAT_CONFIG, LOG_DEBUG, "Configuration loaded\n");
    OtaManager::init();

    SdStorage::init();
    CustomSettings::init();

    Arbiter::init(Serial1, PIN_AS10_RX, PIN_AS10_TX);
    Log::logf(CAT_ARB, LOG_DEBUG, "Initialization returned\n");
    LiveStream::init();
    LiveTce::register_parser();

    // Before WiFi, which can block for a minute during SmartConfig.
    StatusScreen::init();

    bool wifi_ok = WiFiSetup::init();

    TcpBridge::init();

    if (wifi_ok) {
        auto &cfg = Config::get();
        if (cfg.debug_port > 0 && cfg.debug_port != cfg.tcp_port)
            TcpBridge::init_debug_server(cfg.debug_port);

        if (cfg.http_port > 0 && cfg.http_port != cfg.tcp_port)
            WebUI::init(cfg.http_port);
    }

    // If NTP didn't sync, fall back to resmed device clock
    if (!WiFiSetup::time_synced()) Air10Clock::pull_time();

    OxiArbiter::init();
    OxiBle::init();
    OxiUdp::init();

    EdfRecorder::init();
    SleepReport::init();

    Log::logf(CAT_GENERAL, LOG_DEBUG, "Startup initialization complete\n");
}

// Ask Air10Clock to re-sync the AirSense clock after each NTP refresh (the
// first sync after boot is covered by its own boot-time request) and when the
// local UTC offset changes (daylight saving transition or a new tz setting).
// Air10Clock applies its usual policy: standby only, resmed_time setting.
#define TIME_OFFSET_CHECK_MS 60000

// Local time minus UTC, in seconds (includes DST).
static long utc_offset_seconds(time_t now) {
    struct tm lt, gt;
    localtime_r(&now, &lt);
    gmtime_r(&now, &gt);
    int day = lt.tm_yday - gt.tm_yday;
    if (day > 1) day = -1;          // year boundary: local is Dec 31, UTC is Jan 1
    else if (day < -1) day = 1;     // year boundary: local is Jan 1, UTC is Dec 31
    return day * 86400L + (lt.tm_hour - gt.tm_hour) * 3600L +
           (lt.tm_min - gt.tm_min) * 60L;
}

static void check_time_triggers() {
    static uint32_t seen_ntp_syncs = 0;
    static bool     utc_offset_known = false;
    static long     last_utc_offset = 0;
    static uint32_t last_offset_check_ms = 0;

    uint32_t syncs = WiFiSetup::ntp_sync_count();
    if (syncs != seen_ntp_syncs) {
        bool first = (seen_ntp_syncs == 0);
        seen_ntp_syncs = syncs;
        if (!first) {
            Log::logf(CAT_TIME, LOG_DEBUG, "ResMed clock resync requested: NTP resync\n");
            Air10Clock::request_sync();
        }
    }

    if (utc_offset_known && millis() - last_offset_check_ms < TIME_OFFSET_CHECK_MS) return;
    last_offset_check_ms = millis();
    time_t now = time(nullptr);
    if (now < 1700000000) return;   // no valid time yet
    long offset = utc_offset_seconds(now);
    if (utc_offset_known && offset != last_utc_offset) {
        Log::logf(CAT_TIME, LOG_INFO,
                  "ResMed clock resync requested: UTC offset %+ld -> %+ld min\n",
                  last_utc_offset / 60, offset / 60);
        Air10Clock::request_sync();
    }
    last_utc_offset = offset;
    utc_offset_known = true;
}

void loop() {
    serial_poll();
    ClinicalJobs::tick();
    SleepReport::tick();

#if AB_STORAGE_HAS_SDCARD
    static uint32_t recorder_retry_ms = 0;
    if (millis() - recorder_retry_ms >= 5000) {
        recorder_retry_ms = millis();
        EdfRecorder::init();
    }
#endif

    OtaManager::handle();
    WiFiSetup::check();
    Log::poll();
    TcpBridge::poll_debug_clients();
    WebUI::handle();

    // Suspend WiFi scanning during therapy/streaming/oximetry/OTA
    system_state_t sys_st = Arbiter::get_state();
    bool oxi_active = OxiArbiter::is_feeding();
    bool ota_active = (sys_st == SYS_OTA_AIRSENSE || sys_st == SYS_OTA_ESP);

    if (sys_st == SYS_THERAPY || sys_st == SYS_TRANSPARENT ||
        ota_active || oxi_active) {
        WiFiSetup::suspend_roaming();
    } else {
        WiFiSetup::resume_roaming();
    }

    static bool prev_ota_active = false;
    if (ota_active) {
        OxiBle::suspend();
        if (!prev_ota_active && sys_st == SYS_OTA_ESP) LiveStream::suspend();
    } else {
        OxiBle::resume();
        if (prev_ota_active) LiveStream::resume();
    }
    prev_ota_active = ota_active;

    check_time_triggers();
    Air10Clock::handle();

    LiveWebConsumer::tick();
    StatusScreen::tick();

    OxiArbiter::poll();

    AirSenseState::poll();
    Air10Stream::poll();

    delay(10);
}

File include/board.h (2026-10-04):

#pragma once


// UART1 -> AirSense USART3
#ifndef AB_AS10_TX_GPIO
#define AB_AS10_TX_GPIO 26
#endif

#ifndef AB_AS10_RX_GPIO
#define AB_AS10_RX_GPIO 36      // input-only on M5Stamp Pico
#endif

// Drive the AirSense TX pin open-drain (relies on an external pull-up). For
// wiring where TX shares a line with other open-drain devices, e.g. I2C.
#ifndef AB_AS10_TX_OPEN_DRAIN
#define AB_AS10_TX_OPEN_DRAIN 0
#endif

// Touch controller reset; held low at boot to keep it off a shared I2C bus
// (-1 = leave alone)
#ifndef AB_TOUCH_RST_GPIO
#define AB_TOUCH_RST_GPIO -1
#endif

#ifndef AB_LED_GPIO
#define AB_LED_GPIO 27
#endif

// LCD backlight; driven low at boot until the status screen takes over (-1 = none)
#ifndef AB_LCD_BL_GPIO
#define AB_LCD_BL_GPIO -1
#endif

// ST7789 240x240 SPI status screen (src/status_screen.cpp). 0 = no screen.
#ifndef AB_LCD_ENABLED
#define AB_LCD_ENABLED 0
#endif

#ifndef AB_LCD_MOSI_GPIO
#define AB_LCD_MOSI_GPIO -1
#endif

#ifndef AB_LCD_SCLK_GPIO
#define AB_LCD_SCLK_GPIO -1
#endif

#ifndef AB_LCD_CS_GPIO
#define AB_LCD_CS_GPIO -1
#endif

#ifndef AB_LCD_DC_GPIO
#define AB_LCD_DC_GPIO -1
#endif

#ifndef AB_LCD_RST_GPIO
#define AB_LCD_RST_GPIO -1
#endif

// Backlight PWM duty (0-1023) when idle. Tune on hardware to the lowest
// level that is still readable in a dark room.
#ifndef AB_LCD_DIM_DUTY
#define AB_LCD_DIM_DUTY 8
#endif

// How long a button press keeps the backlight at full brightness
#ifndef AB_LCD_WAKE_MS
#define AB_LCD_WAKE_MS 10000
#endif

// Active-low buttons that wake the screen (-1 = unused)
#ifndef AB_BTN1_GPIO
#define AB_BTN1_GPIO -1
#endif

#ifndef AB_BTN2_GPIO
#define AB_BTN2_GPIO -1
#endif

#ifndef AB_BTN3_GPIO
#define AB_BTN3_GPIO -1
#endif

// Battery power latch; driven high at boot so the board stays on (-1 = none)
#ifndef AB_POWER_HOLD_GPIO
#define AB_POWER_HOLD_GPIO -1
#endif

#ifndef AB_STORAGE_SDMMC_ENABLED
#define AB_STORAGE_SDMMC_ENABLED 0
#endif

#ifndef AB_SDMMC_WIDTH
#define AB_SDMMC_WIDTH 4
#endif

#ifndef AB_SDMMC_FREQ_KHZ
#define AB_SDMMC_FREQ_KHZ 20000
#endif

#ifndef AB_SDMMC_CLK_GPIO
#define AB_SDMMC_CLK_GPIO -1
#endif

#ifndef AB_SDMMC_CMD_GPIO
#define AB_SDMMC_CMD_GPIO -1
#endif

#ifndef AB_SDMMC_D0_GPIO
#define AB_SDMMC_D0_GPIO -1
#endif

#ifndef AB_SDMMC_D1_GPIO
#define AB_SDMMC_D1_GPIO -1
#endif

#ifndef AB_SDMMC_D2_GPIO
#define AB_SDMMC_D2_GPIO -1
#endif

#ifndef AB_SDMMC_D3_GPIO
#define AB_SDMMC_D3_GPIO -1
#endif

#ifndef AB_STORAGE_HAS_SDCARD
#define AB_STORAGE_HAS_SDCARD (AB_STORAGE_SDMMC_ENABLED != 0)
#endif

// Backward-compatible aliases used by the current firmware.
#define PIN_AS10_TX     AB_AS10_TX_GPIO
#define PIN_AS10_RX     AB_AS10_RX_GPIO
#define PIN_LED         AB_LED_GPIO

// Phase 2: MITM modem interception
// #define MODEM_UART_NUM  2
// #define PIN_MODEM_TX    18
// #define PIN_MODEM_RX    19


#define DEFAULT_HOSTNAME    "airbridge"

#ifndef AB_OTA_RELEASE_TARGET
#if defined(AB_BOARD_WAVESHARE_S3_LCD154) && AB_AS10_TX_GPIO == 42
// Separate target so a release can never swap the SCL/SDA wiring variant
// for the UART-pad one (or vice versa).
#define AB_OTA_RELEASE_TARGET "waveshare-s3-lcd154-i2cpads"
#elif defined(AB_BOARD_WAVESHARE_S3_LCD154)
#define AB_OTA_RELEASE_TARGET "waveshare-s3-lcd154"
#elif defined(AB_BOARD_WAVESHARE_ESP32_S3_GEEK)
#define AB_OTA_RELEASE_TARGET "waveshare-esp32-s3-geek"
#elif defined(AB_BOARD_WROOM_S3)
#define AB_OTA_RELEASE_TARGET "wroom-s3-n16r8-sdmmc4"
#elif defined(AB_BOARD_XIAO_ESP32S3_PLUS) && AB_STORAGE_SDMMC_ENABLED
#define AB_OTA_RELEASE_TARGET "xiao-esp32s3-plus-sdmmc4"
#elif defined(AB_BOARD_XIAO_ESP32S3_PLUS)
#define AB_OTA_RELEASE_TARGET "xiao-esp32s3-plus"
#else
#define AB_OTA_RELEASE_TARGET "m5stamp-pico"
#endif
#endif

#ifndef AB_DEFAULT_UPDATE_URL
#define AB_DEFAULT_UPDATE_URL                                                \
    "https://github.com/m-kozlowski/airbridge/releases/latest/download/"   \
    "airbridge-release.json"
#endif

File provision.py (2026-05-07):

#!/usr/bin/env python3
"""
AirBridge provisioning script.

Reads key=value pairs from provision.env and sends them to the device
via serial $CONFIG SET commands. Can be run standalone or hooked into
the PlatformIO upload process via extra_scripts.

Usage:
    python provision.py [port]           # explicit serial port
    python provision.py                  # auto-detect from platformio
    pio run -t provision                 # via PlatformIO target
"""

import sys
import os
import shlex
import time
import serial
import serial.tools.list_ports

try:
    _script_dir = os.path.dirname(os.path.abspath(__file__))
except NameError:
    _script_dir = os.getcwd()
PROVISION_FILE = os.path.join(_script_dir, "provision.env")
EXAMPLE_FILE = PROVISION_FILE + ".example"
BAUD = 115200
TIMEOUT = 2




def parse_provision_file(path):
    entries = []
    with open(path, "r") as f:
        for line in f:
            line = line.strip()
            if not line or line.startswith("#"):
                continue
            if "=" not in line:
                continue
            key, _, value = line.partition("=")
            key = key.strip()
            value = value.strip()
            if key and value:
                entries.append((key, value))
    return entries


_LOG_PREFIXES = ("[OXI]", "[TCP]", "[WIFI]", "[OTA]", "[WEB]", "[ARB]",
                 "[HEALTH]", "[DBG]", "[INIT]", "[MIG]", "[GENERAL]")


def _is_log_line(line):
    return any(line.startswith(p) for p in _LOG_PREFIXES)


def send_command(ser, cmd, expect_ok=True):
    ser.reset_input_buffer()
    ser.write((cmd + "\n").encode())
    ser.flush()

    # Read line-by-line filtering async log noise. Stop when the serial goes idle
    ser.timeout = 0.3
    lines = []
    deadline = time.time() + TIMEOUT
    while time.time() < deadline:
        raw = ser.readline()
        if not raw:
            if lines:
                break  # idle
            continue
        line = raw.decode(errors="ignore").rstrip("\r\n")
        if not line:
            continue
        if _is_log_line(line):
            continue
        lines.append(line)
    return "\n".join(lines)


def provision(port):
    if not os.path.exists(PROVISION_FILE):
        print(f"[*] No {os.path.basename(PROVISION_FILE)} found.")
        if os.path.exists(EXAMPLE_FILE):
            print(f"    Copy {os.path.basename(EXAMPLE_FILE)} to {os.path.basename(PROVISION_FILE)}")
            print(f"    and fill in your values, then run: python provision.py")
        return False

    entries = parse_provision_file(PROVISION_FILE)
    if not entries:
        print("[*] provision.env is empty or has no values set, skipping.")
        return True

    print(f"[*] Provisioning {len(entries)} settings via {port}...")

    try:
        ser = serial.Serial(port, BAUD, timeout=TIMEOUT)
    except serial.SerialException as e:
        print(f"[!] Cannot open {port}: {e}")
        return False

    time.sleep(2)
    ser.reset_input_buffer()

    resp = send_command(ser, "$STATUS")
    if "system" not in resp.lower() and "idle" not in resp.lower():
        time.sleep(1)
        resp = send_command(ser, "$STATUS")
        if "system" not in resp.lower() and "idle" not in resp.lower():
            print(f"[!] Device not responding. Got: {resp[:100]}")
            ser.close()
            return False

    print("[+] Device responding")

    errors = 0
    for key, value in entries:
        if key == "wifi_net":
            # value is "ssid password" with shell-style quoting for fields
            # that contain spaces. Routed through $WIFI ADD instead of
            # $CONFIG since multi-network state lives in its own NVS table.
            try:
                parts = shlex.split(value)
            except ValueError:
                parts = []
            ssid = parts[0] if parts else ""
            if not ssid:
                print(f"    wifi_net: SKIPPED (empty)")
                continue
            resp = send_command(ser, f"$WIFI ADD {value}")
            if resp.startswith("OK"):
                print(f"    wifi_net = {ssid} ****")
            else:
                print(f"    wifi_net ({ssid}): FAILED ({resp})")
                errors += 1
            continue

        resp = send_command(ser, f"$CONFIG {key} {value}")
        if resp.startswith("OK"):
            print(f"    {key} = {value if 'pass' not in key else '****'}")
        else:
            print(f"    {key}: FAILED ({resp})")
            errors += 1

    resp = send_command(ser, "$CONFIG SAVE")
    if "OK" in resp or "ok" in resp:
        print("[+] Config saved to NVS")
    else:
        print(f"[!] Save failed: {resp}")
        errors += 1

    print("[*] Rebooting...")
    send_command(ser, "$REBOOT", expect_ok=False)

    ser.close()

    if errors:
        print(f"[!] Provisioning completed with {errors} errors")
    else:
        print("[+] Provisioning complete")

    return errors == 0


def main():
    if len(sys.argv) < 2:
        print(f"Usage: python {os.path.basename(sys.argv[0])} <serial-port>")
        print(f"  e.g. python {os.path.basename(sys.argv[0])} /dev/ttyUSB0")
        sys.exit(1)

    success = provision(sys.argv[1])
    sys.exit(0 if success else 1)


try:
    Import("env")

    def pio_after_upload(source, target, env):
        protocol = env.GetProjectOption("upload_protocol", "esptool")
        if protocol != "esptool":
            return  # skip for OTA and other non-serial protocols
        upload_port = env.get("UPLOAD_PORT")
        if upload_port:
            provision(upload_port)

    env.AddPostAction("upload", pio_after_upload)
except Exception:
    pass  # Not running under PlatformIO

if __name__ == "__main__":
    main()

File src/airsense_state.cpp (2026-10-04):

#include "airsense_state.h"
#include "uart_arbiter.h"
#include "device_uptime.h"
#include "air10_clock.h"
#include "hex_util.h"
#include "custom_settings.h"
#include "live_stream.h"
#include "edf_recorder.h"
#include "export_sync.h"
#include "web_ui.h"
#include "debug_log.h"
#include <atomic>
#include <limits.h>

namespace AirSenseState {
namespace {
constexpr uint32_t ROP_POLL_INTERVAL_MS = 5000;
constexpr uint32_t HEALTH_POLL_INTERVAL_MS = 10000;
constexpr uint16_t HEALTH_TIMEOUT_MS = 500;
constexpr uint32_t MHR_POLL_INTERVAL_MS = 30UL * 60 * 1000;

uint32_t last_rop_poll = 0, last_health_poll = 0, last_mhr_poll = 0;
uint32_t consecutive_timeouts = 0, airsense_seen_ms = 0;
bool airsense_present = false;
std::atomic<int> cached_rop{-1}, cached_mhr{-1}, cached_mop{-1};
std::atomic<bool> refresh_requested{false};
DeviceUptime::Tracker device_uptime;
Identity device_identity;
portMUX_TYPE identity_mux = portMUX_INITIALIZER_UNLOCKED;
std::atomic<uint32_t> device_revision{0};
const char *identity_failed_tag = nullptr, *identity_failure = nullptr;

enum class ReadStep : uint8_t { None, Rop, Stk, Srn, Mid, Vid, Pna, Mop, Mhr, Bls };
ReadStep read_step = ReadStep::None;
uart_transaction_t *read_ticket = nullptr;
uint32_t read_generation = 0;
Identity identity_read;
bool health_requested = false, mhr_requested = false;

static const char *read_tag() {
    static const char *tags[] = {"", "ROP", "STK", "SRN", "MID", "VID", "PNA", "MOP", "MHR", "BLS"};
    return tags[static_cast<unsigned>(read_step)];
}

static bool accept_identity_field(const char *tag, const char *text,
                                   Arbiter::VarResult result, Arbiter::VarReadTrace &trace,
                                   char *out, size_t capacity, uint16_t *number = nullptr) {
    uint32_t parsed = 0;
    if (result == Arbiter::VarResult::Ok) {
        if (!text[0] || strlen(text) >= capacity || strchr(text, '\r') || strchr(text, '\n')) {
            result = Arbiter::VarResult::Failed;
            trace.outcome = "invalid_text";
        } else if (number && !aircannect::parse_hex(text, strlen(text), parsed)) {
            result = Arbiter::VarResult::Failed;
            trace.outcome = "invalid_hex";
        } else if (number && parsed > UINT16_MAX) {
            result = Arbiter::VarResult::Failed;
            trace.outcome = "out_of_range";
        }
    }
    if (result != Arbiter::VarResult::Ok) {
        const bool changed = !identity_failed_tag || strcmp(identity_failed_tag, tag) ||
            !identity_failure || strcmp(identity_failure, trace.outcome);
        identity_failed_tag = tag;
        identity_failure = trace.outcome;
        Log::logf(CAT_HEALTH, changed ? LOG_WARN : LOG_DEBUG,
                  "Identity #%s result=%s queue=%lums sent=%u wait=%lums value=%s\n",
                  tag, trace.outcome, (unsigned long)trace.queue_ms,
                  unsigned(trace.sent), (unsigned long)trace.wait_ms, text);
        return false;
    }
    memcpy(out, text, strlen(text) + 1);
    if (number) *number = static_cast<uint16_t>(parsed);
    return true;
}

static void accept_rop(const char *text, Arbiter::VarResult result,
                        const Arbiter::VarReadTrace &trace) {
    airsense_present = result == Arbiter::VarResult::Ok &&
        (!strcmp(text, "0000") || !strcmp(text, "0001"));
    if (airsense_present) {
        consecutive_timeouts = 0;
        airsense_seen_ms = millis();
        const int new_rop = text[3] - '0';
        const int prev_rop = cached_rop.exchange(new_rop);
        const auto state = Arbiter::get_state();
        if (new_rop == 1 && state == SYS_IDLE) {
            Arbiter::set_state(SYS_THERAPY);
            Log::logf(CAT_HEALTH, LOG_INFO, "Therapy started\n");
            ExportSync::therapy_started();
        } else if (new_rop == 0 && state == SYS_THERAPY) {
            Arbiter::set_state(SYS_IDLE);
            Log::logf(CAT_HEALTH, LOG_INFO, "Therapy ended\n");
            EdfRecorder::request_stop();
            Air10Clock::request_post_therapy_sync();
            mhr_requested = true;
        }
        if (new_rop != prev_rop) WebUI::push_status_event();
        health_requested |= new_rop != prev_rop;
        if (health_requested) last_health_poll = last_rop_poll;
        read_step = health_requested ? ReadStep::Stk : ReadStep::None;
        return;
    }

    ++consecutive_timeouts;
    Log::logf(CAT_HEALTH, LOG_DEBUG,
              "ROP poll failed (%lu consecutive) result=%s queue=%lums sent=%u wait=%lums value=%s\n",
              (unsigned long)consecutive_timeouts, trace.outcome,
              (unsigned long)trace.queue_ms, unsigned(trace.sent),
              (unsigned long)trace.wait_ms, text);
    if (consecutive_timeouts >= 3) {
        invalidate_identity();
        Arbiter::set_state(SYS_ERROR);
        Log::logf(CAT_HEALTH, LOG_WARN, "AirSense unavailable: UART unresponsive\n");
    }
    Air10Clock::invalidate();
    cached_mop = -1;
    read_step = ReadStep::None;
}
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

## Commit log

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2026-05-07 WiFi rework: post-review cleanup
    clear pending_pmf_disable at the top of begin_connect and begin_connect_candidate
    Without it, a failed PMF retry that fell through to the next candidate would leak
    the flag and tag the next successful BSSID with HINT_FLAG_PMF_DISABLE incorrectly
    clear hint_refresh_pending in on_connected
    Both the event callback and on_connected fire from the same STA_GOT_IP and used
    to produce two NetworkHints::upsert calls per connect with identical data
    reset low_rssi_count on the roam-switch path
    drop dead last_bg_scan variable and BG_SCAN_INTERVAL_MS macro
2026-05-07 Expand wifi_mode to 5 values; add wifi_country regulatory code
    wifi_mode previously had three values (STA / AP / off). Expand to five
    to give explicit control over the AP-fallback behavior:
    0 auto STA + automatic AP+STA fallback
    1 AP only softAP only, no STA
    2 off WiFi disabled
    3 STA only STA only, no AP fallback ever
    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
2026-05-07 Add LiveStream pub-sub broker for AirSense live data
    LiveStream is the foundation for fanning live data out to multiple
    consumers without touching the device side per consumer.
    live_stream.{h,cpp} is a pub-sub broker for the unsolicited live
    data channel. Parser modules register a stream tag with a decode
    function; consumers subscribe with a callback.
    First parser: LivePmd (mask pressure / respiratory flow / mask leak,
    25 Hz). First consumer: LiveWebConsumer, the web UI's subscriber
    Update the live charts to consume brokered PMD samples, including
    leak data and SSE-driven subscription lifetime, with full 25 Hz
    resolution
    [commands.cpp, main.cpp]
2026-05-07 LiveStream: post-review fixes
    Broker failed to re-subscribe after AirSense reboot.
    Added reattach() that resets the flag and re-subscribes.
    LiveWebConsumer::acquire was calling do_subscribe, which blocks on
    Arbiter::send_cmd waiting for the device ACK. acquire/release now
    only twiddle the counter; tick() does the actual broker subscribe
    Stale 'Idle' status text in the live charts header removed.
    [main.cpp]
2026-05-20 Charts: auto-rescale press/flow/leak Y-axis on overshoot
2026-05-26 fix uart rx buffering and upload guards
    - queue non-live UART frames instead of replacing a single pending frame
    - keep wait_frame event-driven with rx_ready while preserving queued bootloader errors
    - clear stale RX only at request/response boundaries before raw OTA commands
    - track upload kind and require a valid ResMed upload before flash start/status
    - make web upload UI check response ok instead of treating HTTP 200 as success
2026-05-26 isolate uart during resmed ota
    - claim SYS_OTA_AIRSENSE state before bootloader entry
    - wait for in-flight UART commands before raw OTA access
    - require confirmed live-stream unsubscribe before entering bootloader
    - reject non-OTA UART traffic while resmed OTA owns the bus
    - keep ESP OTA on the existing best-effort suspend path
2026-08-27 add xiao esp32s3 plus target
    - make AirSense UART pins configurable per build
    - add XIAO ESP32S3 Plus SDMMC4 and OTA environments
    - document XIAO UART and SDMMC4 pinout
    [partitions_s3_8mb.csv]
2026-09-08 fix stalled wifi connection retries
    - restart pending STA associations without rerunning WiFi.begin
    - preserve retry exhaustion so AP fallback remains reachable
    - skip removal of missing provisioned-network keys
    [app_config.cpp]
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2026-09-22 wait for final air10 str save
    - retry transport failures immediately up to three times while keeping missing values terminal
    - gate collection on the next completed-save ZEN generation after therapy stops
    - confirm the current session through its MaskOn and MaskOff pair
    - replace speculative THD delays with bounded timeout and state-change aborts
2026-09-22 discover airbreak clinical settings
    - discover and cache localized custom setting metadata at runtime
    - merge stock and custom controls into one categorized Clinical screen
    - invalidate cached metadata after language changes, resets, and firmware flashing
    [main.cpp]
2026-09-22 add wroom s3 board target
    [partitions_s3_16mb.csv]
2026-09-22 fix web ui javascript minification
    - vendor pure-Python rjsmin from AirCANnect and preserve raw-text blocks
    - resolve generator paths through PlatformIO without relying on __file__
    - cover SMB strings, generated script syntax and SCons execution
    [generate_web_ui.py]
2026-09-22 add airbridge http ota flasher
    - upload local firmware or build an explicit or detected environment
    - support parallel targets with AirCANnect-style progress reporting
    - confirm upload and reboot without hardcoded board or partition metadata
    - test HTTP transport, reporting and failure handling
2026-09-22 retry uncertain live stream subscriptions
    - retry failed unsubscribe and reclaim unused stream slots
    - reconcile device state after lost subscription acknowledgements
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2026-09-22 bound uart transactions and track resmed clocks
    - own callback contexts and detach cancelled UART transactions safely
    - include queue wait in deadlines and drain late replies before reuse
    - match response echoes and isolate framed TCP connection generations
    - detect AirSense restarts through the hexadecimal 10 ms STK counter
    - separate native STR and export clocks, correcting Date and mask times
    - defer automatic clock writes until SD recording and STR collection finish
    - cover cancellation, recovery, queue lifetime and clocks with sanitizer tests
    [main.cpp]
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2026-09-22 decode str replies verified on air10 hardware
    - finish G V transactions on delayed echoed R replies, including framed TCP
    - decode the STR count as samples rather than bytes
    - validate the echoed tag and therapy day before accepting values
    - treat unsupported signals as absent and retain transport retries
    - add a CRC-verified UART capture from the development AirSense as a fixture
2026-09-22 split live recordings at therapy noon
    - rotate EDF segments at monotonic noon boundaries without stopping live streams
    - retain queued frames and defer STR collection and export until actual standby
    - cover noon rollover, millis wrap and segment initialization failure in host tests
2026-09-22 retry recording startup during active therapy
    - retry recorder initialization, SD mounting and session startup during confirmed therapy
    - retain therapy intent across queue overflow and cancel retries on mask-off
    - preserve the observed mask-on separately from a delayed recording start
    - journal sessions before creating EDF files and keep pending recovery out of export
    - distinguish lost communication from a confirmed mask-off and clean failed allocations
    - prefer PSRAM for the recorder stack and cover retry, replay and cleanup regressions
    [main.cpp]
2026-09-22 fix request isolation and background recovery
    - isolate HTTP bodies and reject incomplete or oversized requests
    - preserve new oximetry sources during timeout and BLE cleanup
    - keep fallback AP available while retrying STA with coexistence scans
    - track unnecessary incremental rebuilds in the backlog
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2026-09-22 tcp: preserve transparent transfers across disconnects
    - drain buffered input to UART before leaving transparent mode
    - queue UART replies and preserve input on TCP send failures
    - wait for RX callbacks and avoid clearing input during baud changes
    - start each new transparent session at 57600
2026-09-22 ota: report TLS failures and memory availability
    - log transport codes, certificate flags and socket errno
    - include failure-time internal heap, largest block and clock
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2026-09-22 memory: install PSRAM-aware TLS allocation before workers
    - make memory and TLS allocation independent of SD support
    - remove lazy memory initialization and export-time TLS replacement
    [main.cpp]
2026-09-22 web: stream live backfill from compact sample snapshots
    - reuse Clinical response buffering and partial-send handling
    - avoid full JSON strings and keep snapshots stable until HTTP cleanup
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2026-09-22 ble: apply NimBLE limits after SDK defaults
    - prevent sdkconfig and legacy aliases from overriding library settings
    - compile central-only single-client support on Pico and esp32-s3
2026-09-22 build: keep generated headers out of the source tree
    - generate WebUI and migration headers per build environment
    - avoid source-tree changes and stale local header shadowing
    [generate_web_ui.py]
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2026-09-23 clinical: identify failed jobs and metadata discovery stages
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2026-09-23 log: separate EDF and stream categories and skip filtered dumps
    [commands.cpp]
2026-09-24 Add support for Waveshare ESP32-S3-LCD-1.54 and update documentation
    - Introduced build environment for Waveshare ESP32-S3-LCD-1.54 in platformio.ini
    - Updated README.md to include supported boards and setup instructions
    - Enhanced hardware.md with wiring details for Waveshare board
    - Modified quickstart.md to reflect new board support and flashing instructions
    - Added GPIO definitions for LCD backlight and power latch in board.h
    - Replaced wifi.h with wifi_setup.h in multiple source files for consistency
    [board.h, commands.cpp, main.cpp]
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2026-09-25 uart: queue LCD updates without blocking callers
    - execute hide, text and show through matched UART transactions
    - stop the sequence on failure and start expiry after acknowledgement
    - keep LCD requests out of exclusive UART modes
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2026-09-26 uart: share the receive parser across normal and transparent modes
    - consume mode and baud reset requests in the RX task
    - retain the separate bounded TX sniffer for simultaneous traffic
2026-09-26 uart: copy only populated RX payload bytes
    - preserve metadata and terminators without copying unused capacity
    - avoid clearing the full payload when queuing short TCP replies
2026-09-26 oxi: reduce scan address allocations and consolidate name prefixes
    - format each advertisement address once and retain it in fixed storage
    - keep complete names only for stored candidates
    - use case-insensitive prefixes consistently for discovery and Nonin
    [commands.cpp]
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2026-09-26 config: share field metadata and skip unchanged NVS writes
    - share defaults, storage keys and secret flags across config paths
    - format listed values directly without another key lookup
    - retain existing NVS names, types and WiFi migration paths
    [app_config.cpp, commands.cpp]
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2026-09-26 clinical: limit idle cleanup to once per second
    - avoid taking job and metadata mutexes on every main loop iteration
    - retain expiration deadlines and immediate slot reuse on submission
2026-09-26 uart: finish scalar error replies without draining the queue
2026-09-26 config: let NVS skip unchanged values and pass redaction flags
    - remove the redundant read and compare pass before saving
    - reuse descriptor flags during HTTP and CLI enumeration
    [app_config.cpp]
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2026-09-26 config: track onboarding and report persistence failures
    [app_config.cpp, commands.cpp]
2026-09-26 web: persist setup completion and apply WiFi changes
    - finish setup only after saving access credentials and its marker
    - keep fallback AP available when the network list is empty
    - report profile save errors without mistaking them for a full list
    [app_config.cpp, commands.cpp]
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2026-09-26 config: reload persisted values after a failed save
    [app_config.cpp]
2026-09-26 wifi: restore persisted profiles after a failed save
    [app_config.cpp]
2026-09-26 edf: use the ResMed clock throughout recording
    - use DAC/TIC for EDF paths, headers and native noon boundaries
    - preserve stored STR dates and mask intervals without clock offsets
    - read native session end time and fix the noon origin of CSR events
    - defer managed clock writes until standby and pending STR completion
    - replace dual-clock journals with v2 without migrating old recordings
    [commands.cpp, main.cpp]
2026-09-26 edf: extend STR to the current Airbreak superset
    - add BRR, RRT, ITT and VSR before the record CRC
    - preserve missing fields for stock and older Airbreak firmware
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2026-09-26 edf: synchronize stored summaries by SSD and ZEN
    - keep observing completed saves in standby after pending work ends
    - collect native days across noon without matching files to mask pairs
    - accept zero duration and distinguish missing records from failures
    - retain day intents across resets and refresh export revisions
    - invalidate generation tracking when STK detects a device restart
    [main.cpp]
2026-09-26 edf: keep clock writes blocked across a restart race
    - recheck device generation when publishing STR synchronization state
    - retain revision-zero wire fixtures and recording protocol evidence
2026-09-26 ota: erase upload partitions in bounded blocks
    - avoid whole-slot erase blocking the HTTP task
    - retain 64 KiB erase speed and abort failed erase operations
2026-09-26 edf: add alveolar ventilation and ratio channels to PLD
    Read AAV, RCR and RTR through the existing two-second sampler.
    Match Airbreak channel order and scales; preserve missing values.
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2026-09-28 storage: add rename and recursive delete in UI and CLI
    - reuse storage admission and cancellation for file mutations
    - allow internal files and report partial deletion failures
    - add Rename, Delete selected and asynchronous CLI commands
    [commands.cpp]
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2026-09-28 web: retry SSE only for clients that missed the state
    - track bounded per-client delivery instead of replaying broadcasts
    - deliver initial OTA and export state only to the new connection
    - identify WiFi invalidations by revision to suppress duplicate reads
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2026-09-28 web: avoid list refreshes and invisible update events
    - refresh BLE collections only when their contents or config change
    - preserve current pushed readings across delayed collection replies
    - suppress hidden OTA blocking changes and remove redundant status GETs
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2026-09-28 flasher: shorten reboot probes and report stage timings
    - cap reboot API probe socket timeouts at two seconds
    - report upload and restart stage durations separately
    - show the actual exception when a reboot request loses its reply
2026-09-28 config: remove unused options and fix UART startup baud
    - rename the AirSense UART category to UART
    - remove unused mitm_mode and oxi_device_type settings
    - start UART at 57600 without a configurable baud rate
    - retain bootloader baud negotiation and current baud reporting
    [app_config.cpp, main.cpp]
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2026-09-28 edf: decouple clock writes from catalog and STR readiness
    - inventory pending journals before catalog recovery and UART reads
    - block clock writes for pending work, not failed STR synchronization
    - clear collection state on early returns and log deferral reasons
    [main.cpp]
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2026-09-28 edf: avoid redundant STR refreshes and exports
    - cache Identification per device boot and verify its files before reuse
    - revisit the previous day only after startup, rollover or missed saves
    - skip identical STR rewrites and use content-based export revisions
    - retain pending intents until file and catalog publication complete
    - retry rejected export requests without waiting for another save
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2026-09-28 ota: cache derived blocking and ArduinoOTA eligibility
    - recompute blocking reasons only when admission inputs change
    - replace full export snapshots with the atomic activity query
    - retain live checks when starting updates and local AP ArduinoOTA
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2026-09-28 uart: distinguish missing scalars and share hex reads
    - classify E 6009 without confusing it with an R value
    - use the shared reader in Clinical, reports, EDF and health
    - retain caller deadlines, cache generations and numeric limits
    [main.cpp]
2026-09-28 export: reject unavailable manual actions with owner reasons
    - share admission rules between UI, HTTP and CLI
    - keep automatic startup and post-therapy requests deferred
    - return specific rejection and queue failure reasons
    [commands.cpp]
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2026-09-28 oxi: keep background scans and memory diagnostics off INFO
    - report scan candidates without claiming verified oximeters
    - distinguish BLE links from subscribed sensors
    - summarize connection failures and suppress unchanged automatic retries
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2026-09-28 log: report configuration and OTA outcomes in their own categories
    - include failure reasons for Clinical and report jobs
    - expose NVS write failures without logging stored values
    - remove routine startup and update-check chatter
    [app_config.cpp, main.cpp]
2026-09-28 log: retain failure context and honest clock provenance
    - keep repeated UART drops and malformed UDP packets at DEBUG
    - include rejected AirSense fields in the save outcome
    - clear NTP provenance after explicitly applying ResMed time
2026-09-28 pcb: add interface_board kicad project
    [interface.kicad_pcb, interface.kicad_sch]
2026-09-28 pcb: add main_board Xiao S3 Plus flavour kicad project
    [main.kicad_pcb, main.kicad_sch]
2026-09-28 pcb: add main_board WROOM flavour kicad project
    [main.kicad_pcb, main.kicad_sch]
2026-09-28 pcb: add interface, main_xiao, main_wroom gerbers
    [interface-B_Cu.gbr, interface-B_Mask.gbr, interface-B_Paste.gbr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]
2026-09-28 pcb: add assembly files for interface board (BOM, CPL)
    [bom-interface.csv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]
2026-09-28 pcb: add assembly files for xiao/wroom main boards (BOM, CPL)
    [bom-main-wroom.csv, bom-main-xiao.csv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]
2026-09-28 hardware: 3d printable enclosure for interface+xiao_main hardware
    [airbridge-xiao.stl]
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2026-09-28 hardware: add schematics for hand-wired hardware variants
    [pico.kicad_sch, xiao.kicad_sch, xiao_sd.kicad_sch]
2026-09-28 docs: update v2 hardware variants and setup
    - document PCB and hand-wired XIAO builds with and without SD
    - clarify SD requirements and limited Pico support
    - remove OTA environment examples and obsolete repartitioning guide
    [makeshift_enclosure.stl]
2026-09-28 docs: fix kicad projects links
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2026-09-28 build: remove the obsolete partition migrator
    [partitions_v1.csv]
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2026-09-29 edf: temporarily log failed PLD reads with UART timing
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2026-10-01 oxi: apply passive observation and reconnect policy
    - Connect only to opted-in known sensors, without waiting for scan end.
    - Back off failed attempts and hold intentional disconnects per sensor.
    - Disconnect silent, invalid and charging sources in the BLE task.
    - Keep measurement freshness unchanged pending a separate review.
    [app_config.cpp]
2026-10-01 oxi: keep the full reconnect pause after missing measurements
    Do not infer sensor shutdown from gaps in sparse BLE observation.
    Leave silent or invalid sources alone for the full three minutes.
    Manual Connect still bypasses the holdoff.
2026-10-01 oxi: shorten gaps in passive sensor observation
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2026-10-01 device: share AirSense identity across status and EDF
    Let AirSenseState publish one generation-checked identity snapshot.
    Remove the Config cache and repeated SRN/MID/VID reads from consumers.
    Reuse cached fields when collecting Identification after therapy.
    Invalidate on restart, confirmed UART loss and ResMed bootloader entry.
    Keep recording identity separate from standby STR jobs and report
    failed metadata tags with their UART transaction outcome.
    [airsense_state.cpp, app_config.cpp, commands.cpp]
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2026-10-02 streams: discover schemas once per device identity
    Share an identity-bound schema cache between recording and live charts.
    Collect layouts asynchronously instead of querying at therapy start or
    stream enable. Invalidate them on device restart or identity loss.
    Only refused discovery selects stock layouts; retry failed reads without
    publishing partial or stale metadata.
    [air10_stream.cpp, main.cpp]
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2026-10-02 crash: reserve flash for core dumps and retain release ELF files
    [partitions.csv, partitions_s3_16mb.csv, partitions_s3_8mb.csv]
2026-10-02 crash: enlarge S3 dumps to 256 KiB with equal OTA slots
    [partitions_s3_16mb.csv, partitions_s3_8mb.csv]
2026-10-02 crash: expose retained dumps through CLI and HTTP
    - share validated status and summary between CLI and HTTP
    - map flash for bounded downloads and reject clear while downloading
    - keep invalid dumps until an explicit clear
    [commands.cpp, main.cpp]
2026-10-02 web: report UART command failures instead of OK
    Return the arbiter failure reason and retain device error replies.
    Require explicit success before the console displays OK.
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2026-10-03 hardware: airbridge-xiao.stl lid adjustment
    [airbridge-xiao.stl]
2026-10-04 pcb: interface-board: flip inverted U2 U7
    [cpl-interface.csv]
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2026-10-05 report: simplify selection and stabilize EDF charts
    Show recorded days in the calendar; toggle sessions with compact pills.
    Filter hidden sessions before series aggregation and event collection.
    Use stable shared pressure axes and per-chart cursor values.
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2026-10-06 report: stabilize loading and compact linked charts
    - Reuse available days until the dataset or connection changes.
    - Preserve the displayed report while a replacement loads.
    - Align touch and high-DPI canvases with the shared time axis.
    - Group pressures, select channels and show CSR on the event strip.
2026-10-06 report: reuse formatted values across identical chart buckets
    Avoid repeated float formatting without changing wire values or caches.
    Expose bounded worker-stage timing at EDF DEBUG level.
2026-10-06 report: cosmetic fixes for v2 report view
    - remove the separate overview chart
    - keep Events visible in empty chart windows
    - expand channel statistics by default
    - place sessions and zoom controls in Charts
    - remove the coverage column from channel statistics
    - combine day and period selection
    - show only statistics for multi-day periods
    - avoid excessive padding on the Flow axis
2026-10-07 system: add factory reset for NVS and SD
    Reset configuration and recreate a single FAT32 partition on SD.
    Run destructive work before normal startup and preserve firmware.
    [commands.cpp, main.cpp]
2026-10-08 hardware: ratsnest-SD enclosure model to fit hand-wired hardware
    [as10-side-adapter-ratsnest.stl]
2026-10-09 GPIO0 button fix
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2026-10-09 http: patch send credits without modifying installed libraries
    - Port AirCANnect patching to generated build sources.
    - Keep flow control without consuming credits on empty sends.
    - Count short TCP writes and preserve credit for unsent headers.
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2026-10-09 crash: announce retained dumps after syslog configuration loads
    [main.cpp]
2026-10-09 log: retain failure context for syslog socket and send errors
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2026-10-09 edf: explain STR refresh outcomes and export delays
    Replace INFO catalog commits with recorder-owned STR outcomes, ZEN
    brackets, readiness changes and read/SD timings. Keep routine catalog
    commits at DEBUG and report export wait time from enqueue.
2026-10-21 Add read-only ResMed UART link test
    $FLASH LINKTEST <57600|115200|460800> [count] enters the AirSense
    bootloader like a dump, switches to the requested speed, repeats
    G S #BLS status reads and returns to the application. It never erases,
    writes or reads flash. Results separate missing replies (likely TX
    corruption) from RX CRC errors, to check whether the open-drain TX on
    the i2cpads wiring is safe for a bootloader write at 460800 baud.
    See docs/resmed_link_test.md.
